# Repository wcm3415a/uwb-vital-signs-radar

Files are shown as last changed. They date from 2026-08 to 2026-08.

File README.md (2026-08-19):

# UWB Radar for Contactless Vital Sign Detection





## 📋 Overview
This repository contains the hardware configuration, firmware, and signal processing software for a proof-of-concept UWB radar system. The objective was to design a contactless Ultra-Wideband (UWB) radar system to detect vital signs for future integration into a mobile robot. This research relies on repurposing low-cost DWM1001-DEV modules into a bistatic radar to extract and analyze the Channel Impulse Response (CIR).

This project was conducted as part of a 4th-year engineering internship at the **HCR Laboratory (Robotics and Embedded Systems)** at **[Ostfalia University of Applied Sciences, Germany](https://www.ostfalia.de)**.

## 📚 Project Documentation (Wiki)
Comprehensive documentation covering the theoretical background, hardware setup, and software architecture is available in the **[Project Wiki](https://github.com/wcm3415a/uwb-vital-signs-radar/wiki)**:
* 📖 **[Hardware Architecture and Test Bench](https://github.com/wcm3415a/uwb-vital-signs-radar/wiki/Hardware-and-Test-Bench):** Details on the bistatic configuration and the 3D-printed electromagnetic shield.
* 📖 **[Firmware and SPI Communication](https://github.com/wcm3415a/uwb-vital-signs-radar/wiki/Firmware-and-SPI):** C++ implementation, register modifications, and SPI throttling.
* 📖 **[DSP Theory and VMD Algorithm](https://github.com/wcm3415a/uwb-vital-signs-radar/wiki/Signal-Processing):** Mathematical foundations of phase extraction and Variational Mode Decomposition.
* 📖 **[Real-Time Python Application](https://github.com/wcm3415a/uwb-vital-signs-radar/wiki/Python-Application):** Multithreaded architecture for high-speed serial parsing and real-time visualization.

## 🛠️ System Architecture
* **Firmware (C++):** A custom low-level firmware developed via PlatformIO bypasses the factory localization features. The transmitter operates at 64 MHz PRF (Channel 5), while the receiver continuously extracts the CIR. SPI communication is throttled to 1 MHz to prevent data corruption.
* **Hardware Mitigation:** A custom 3D-printed shield lined with aluminum prevents receiver saturation caused by direct antenna coupling.
* **Software Pipeline (Python):** An asynchronous multithreaded application parses the 460,800-baud serial stream. It applies an Exponential Moving Average for radar clutter removal, extracts the complex phase (`arctan(Q/I)`), and uses Variational Mode Decomposition (VMD) to isolate physiological frequencies.

## 📊 Experimental Results and Hardware Limitations
The software processing chain was successfully validated on the [MobiVital](https://github.com/nesl/MobiVital-dataset) reference dataset, achieving a respiratory rate estimation error of less than 8%. However, real-world testing on the physical prototype revealed strict hardware limitations:

* **Respiration Extraction:** The system successfully extracts the respiratory signal, allowing the distinction between inspiration and expiration cycles. However, the measurement is affected by a permanent residual noise that cannot be fully compensated by software, occasionally falsifying parts of the obtained results.
* **Heart Rate Extraction (Failed):** Heartbeat extraction failed due to absolute physical limitations. The lack of strict hardware clock synchronization between the two asynchronous boards induces a phase noise (Jitter). This electronic drift completely masks the sub-millimeter cardiac displacement, rendering it unexploitable. Future iterations will strictly require hard-wired clock synchronization.

## 📁 Repository Structure
```text
├── Firmware/                 # C++ PlatformIO project for TX/RX modules
│   ├── src/main.cpp          # Core radar logic and SPI extraction
│   └── lib/                  # DW1000 low-level API headers
├── Software/                 # Python DSP pipeline and analysis scripts
│   ├── analysis_breath_DB.py # Respiratory extraction on MobiVital reference dataset
│   ├── analysis_breath_RT.py # Real-time respiratory extraction from serial UWB stream
│   ├── analysis_puls_DB.py   # Heart rate extraction tests on reference dataset
│   └── fonction_RPM.py       # Core DSP functions (VMD, Phase extraction, EMA filters)
├── Hardware/                 # 3D models (STL/Fusion 360) for the RF shield
└── Docs/                     # Additional documentation and test data
```
##  References
This project and its signal processing methodology are based on the following scientific literature and datasets:

* L. Duan et al., "Non-Contact Detection of Vital Signs Using a UWB Radar Sensor", *IEEE Access*, vol. 6, 2018. [DOI: 10.1109/ACCESS.2018.28581412](https://ieeexplore.ieee.org/document/8581412)
* S. Ma et al., "Radar Vital Signs Detection Method Based on Variational Mode Decomposition and Wavelet Transform", *IEEE Sensors Journal*, 2021. [DOI: 10.1109/JSEN.2022.31528129](https://ieeexplore.ieee.org/document/9728129)
* J. Wang et al., "SSA-VMD for UWB Radar Sensor Vital Sign Extraction", *MDPI Sensors*, vol. 23, 2023. [DOI: 10.3390/s23020756](https://www.mdpi.com/1424-8220/23/2/756)
* G. Paterniani et al., "Radar-Based Monitoring of Vital Signs: A Tutorial Overview", *Proceedings of the IEEE*, vol. 111, no. 3, pp. 277-317, March 2023. [DOI: 10.1109/JPROC.2023.32449295](https://ieeexplore.ieee.org/stamp/stamp.jsp?arnumber=10049295)
* Networked & Embedded Systems Lab (NESL), "MobiVital-dataset", *GitHub Repository*. [Link](https://github.com/nesl/MobiVital-dataset)

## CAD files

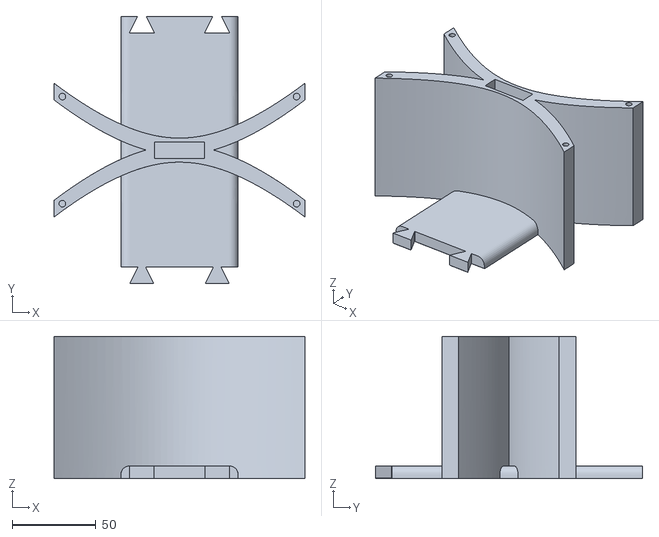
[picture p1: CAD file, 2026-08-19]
Hardware/CentreAvObsB.stl
150.0 x 159.8 x 85.0

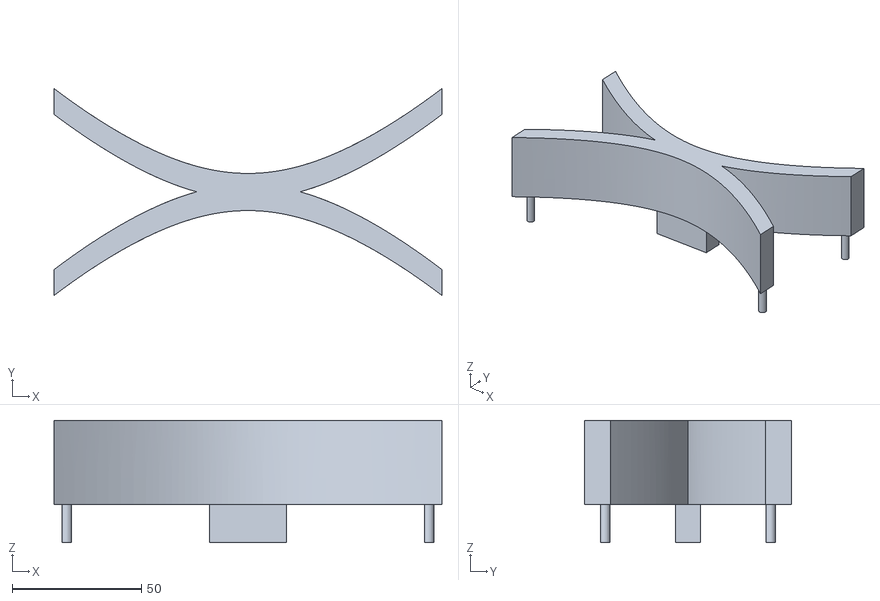
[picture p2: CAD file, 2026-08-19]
Hardware/CentreAvObsH.stl
150.0 x 80.0 x 47.4

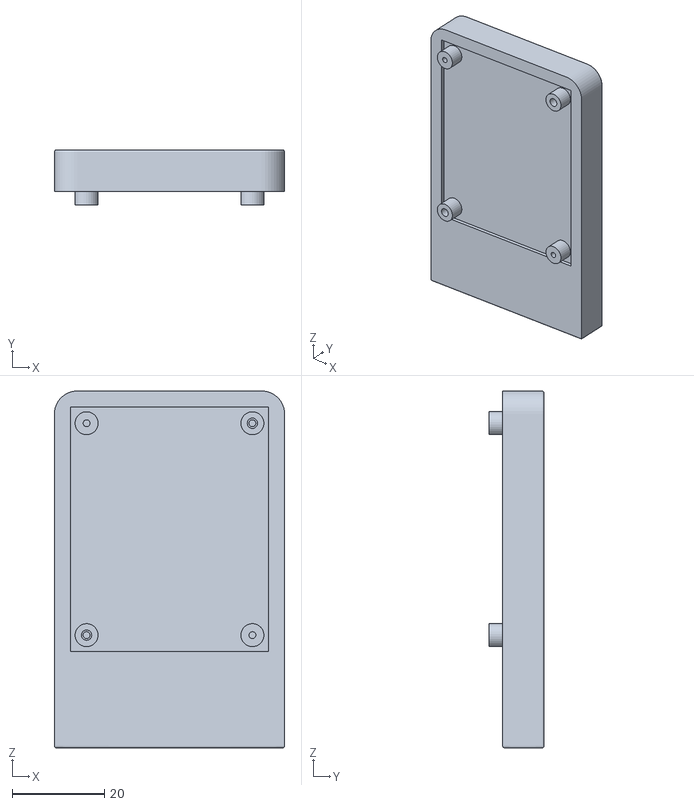
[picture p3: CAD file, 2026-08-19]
Hardware/Support2.stl
50.0 x 12.0 x 77.5

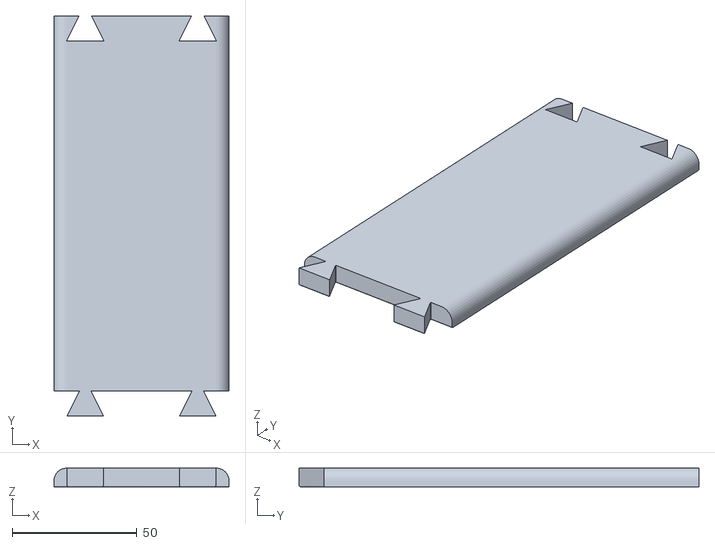
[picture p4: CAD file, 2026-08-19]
Hardware/CentreSaObs.stl
70.0 x 159.8 x 7.50

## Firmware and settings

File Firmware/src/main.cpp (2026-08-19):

#include <Arduino.h>
#include "deca_device_api.h"
#include "deca_regs.h"
 
// --- RADAR ROLE TOGGLE ---
bool is_tx_module = false; 
#define PIN_SW2 2          

extern "C" void port_init(void);

// --- UWB RADIO CONFIGURATION (Radar Special) ---
static dwt_config_t config = {
    5,               // chan           : Radio channel (Channel 5 = 6.5 GHz)
    DWT_PRF_64M,     // prf            : Pulse Repetition Frequency (64 MHz)
    DWT_PLEN_128,    // txPreambLength : Preamble length (128 symbols)
    DWT_PAC8,        // rxPAC          : Preamble Acquisition Chunk 
    9,               // txCode         : TX preamble code 
    9,               // rxCode         : RX preamble code 
    0,               // nsSFD          : Non-standard SFD 
    DWT_BR_6M8,      // dataRate       : Data rate (6.8 Mbps) 
    DWT_PHRMODE_STD, // phrMode        : PHY header mode 
    (129 + 8 - 8)    // sfdTO          : SFD Timeout 
};

void setup() {
    Serial.begin(460800); 
    
    // 1. DEEP SLEEP WAKE-UP
    pinMode(17, OUTPUT);
    digitalWrite(17, LOW);  
    delay(5);               
    digitalWrite(17, HIGH); 
    delay(10);              
    
    // 2. HARDWARE RESET (Pin 24)
    pinMode(24, OUTPUT);
    digitalWrite(24, LOW);  
    delay(10);
    pinMode(24, INPUT);     
    delay(50);              

    // 3. SPI BUS OPENING 
    port_init();
    
    // 4. FORCED PATCH: CAPPING SPI SPEED TO 1 MHz
    #ifdef NRF_SPI2
        NRF_SPI2->FREQUENCY = 0x01000000;
        NRF_SPI2->CONFIG = 0;
    #endif
    #ifdef NRF_SPIM2
        NRF_SPIM2->FREQUENCY = 0x01000000;
        NRF_SPIM2->CONFIG = 0;
    #endif
    #ifdef NRF_SPI1
        NRF_SPI1->FREQUENCY = 0x01000000;
        NRF_SPI1->CONFIG = 0;
    #endif
    #ifdef NRF_SPIM1
        NRF_SPIM1->FREQUENCY = 0x01000000;
        NRF_SPIM1->CONFIG = 0;
    #endif
    
    // 5. DW1000 software initialization
    dwt_softreset();
    
    if (dwt_initialise(DWT_LOADUCODE) != DWT_SUCCESS) {
        while (1) {
            Serial.println("CRITICAL ERROR: The DW1000 chip is not responding on the SPI bus");
            delay(1000);
        }
    }
    
    dwt_configure(&config);
    dwt_setrxantennadelay(16436);

    // --- READING SW2 BUTTON ---
    NRF_P0->PIN_CNF[2] = (3 << 2); 
    delay(10); 

    if ((NRF_P0->IN & (1 << 2)) == 0) {
        is_tx_module = true; 
    } else {
        is_tx_module = false;
    }

    // --- TURNING ON LEDS ---
    NRF_P0->DIRSET = (1 << 14) | (1 << 30);
    NRF_P0->OUTSET = (1 << 14) | (1 << 30);

    if (is_tx_module) {
        Serial.println("Initialising the TX (20 Hz transmitter)...");
        NRF_P0->OUTCLR = (1 << 14); // Turn on Green LED (D9)
    } else {
        Serial.println("Initialising the RX (Radar Recieve)...");
        NRF_P0->OUTCLR = (1 << 30); // Turn on Blue LED (D10)
    }
}

void loop() {
    if (is_tx_module) {
        // --- TX LOGIC ---
        uint8_t tx_msg[] = {'R', 'A', 'D', 'A', 'R', 0, 0}; 

        dwt_writetxdata(sizeof(tx_msg), tx_msg, 0);
        dwt_writetxfctrl(sizeof(tx_msg), 0, 0);
        dwt_starttx(DWT_START_TX_IMMEDIATE);

        while (!(dwt_read32bitreg(SYS_STATUS_ID) & SYS_STATUS_TXFRS)) {
            // Very short wait for the physical transmission
        }
        dwt_write32bitreg(SYS_STATUS_ID, SYS_STATUS_TXFRS); // Unlocks the next shot

        // Wait for 50 milliseconds (20 Hz)
        delay(50); 

    } else {
        // --- RX LOGIC ---
        dwt_rxenable(DWT_START_RX_IMMEDIATE);

        uint32_t status_reg = 0;
        while (!((status_reg = dwt_read32bitreg(SYS_STATUS_ID)) & (SYS_STATUS_RXFCG | SYS_STATUS_ALL_RX_ERR))) {
            // Waiting for the wave...
        }

        if (status_reg & SYS_STATUS_RXFCG) {
            
            // 1. Read the exact index where the wave hit (First Path)
            uint16_t fp_index = dwt_read16bitoffsetreg(RX_TIME_ID, RX_TIME_FP_INDEX_OFFSET);
            uint16_t fp_int = fp_index >> 6; // Convert raw index to integer

            // 2. Step back 10 samples to see the silence right BEFORE the impact
            int16_t start_index = fp_int - 10;
            if (start_index < 0) {
                start_index = 0; 
            }

            // 3. Convert this index to bytes (1 sample = 4 bytes)
            uint16_t byte_offset = start_index * 4;

            // 4. Anti-crash security: prevent reading out of memory bounds (max 4064)
            if (byte_offset > 3000) {
                byte_offset = 3000; 
            }

            // 5. Clear the flag
            dwt_write32bitreg(SYS_STATUS_ID, SYS_STATUS_RXFCG);

            // 6. Read the accumulator with the CORRECT OFFSET
            uint16_t cir_bytes = 1024; 
            uint8_t cir_buffer[cir_bytes + 1]; 

            dwt_readaccdata(cir_buffer, cir_bytes + 1, byte_offset);

            // Send to Mac
            uint8_t header[] = {0xDE, 0xCA, 0xAD, 0xDE}; 
            Serial.write(header, 4);
            Serial.write(&cir_buffer[1], cir_bytes);

        } else {
            dwt_write32bitreg(SYS_STATUS_ID, SYS_STATUS_ALL_RX_ERR);
        }
    }
}

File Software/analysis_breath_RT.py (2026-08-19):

import matplotlib
matplotlib.use('TkAgg')
import matplotlib.pyplot as plt
import matplotlib.animation as animation
import serial
import struct
import numpy as np
import threading
import traceback
import time
import scipy.ndimage as ndimage
from collections import deque
from vmdpy import VMD

# ==========================================
# HARDWARE CONFIGURATION
# ==========================================
PORT = '/dev/cu.usbmodem0007602221481'  
BAUDRATE = 460800
HEADER = b'\xde\xca\xad\xde'
PAYLOAD_SIZE = 1024
NUM_SAMPLES = 256
DISPLAY_BINS = 100

# ==========================================
# CIR & TARGET PARAMETERS
# ==========================================
ALPHA_FAST = 0.1         
ALPHA_ENV = 0.02 
MOTION_THRESHOLD = 800      
TARGET_BIN = 19  # Fixed target at 60 cm
PHASE_PRESENCE_THRESHOLD = 900

# ==========================================
# RESPIRATION & VMD PARAMETERS
# ==========================================
ESTIMATED_FPS = 15
HISTORY_SIZE = 300
DISPLAY_MARGIN = 15
ALPHA_PHASE_SMOOTHING = 0.15
REFERENCE_THRESHOLD = 400

# ==========================================
# GLOBAL VARIABLES
# ==========================================
lock = threading.Lock()
stop_requested = False
first_sample_received = False
REFERENCE_BIN = 0  

# CIR Buffers
cir_median_buffer = deque(maxlen=3) # NEW: Buffer for median filter
raw_cir = np.zeros(NUM_SAMPLES)
smooth_cir = np.zeros(NUM_SAMPLES)
motion_cir = np.zeros(NUM_SAMPLES)
fast_amp = np.zeros(NUM_SAMPLES)
slow_amp = np.zeros(NUM_SAMPLES)

# Temporal Buffers
history_raw_target_phases = deque(maxlen=HISTORY_SIZE)
history_corrected_phases = deque(maxlen=HISTORY_SIZE)

centered_raw_target_signal = np.zeros(HISTORY_SIZE) 
centered_corrected_phase_signal = np.zeros(HISTORY_SIZE) 
vmd_respiratory_signal = np.zeros(HISTORY_SIZE) 

smooth_I_phase, smooth_Q_phase = 0.0, 0.0
first_phase_sample = False

smooth_I_ref, smooth_Q_ref = 0.0, 0.0
first_ref_sample = False

# Buffers for complex smoothing of the difference
smooth_I_diff, smooth_Q_diff = 0.0, 0.0
first_diff_sample = False

# ==========================================
# THREAD 1: RADAR PROCESSING (REAL-TIME)
# ==========================================
def read_serial():
    global raw_cir, smooth_cir, motion_cir, fast_amp, slow_amp
    global smooth_I_phase, smooth_Q_phase, first_phase_sample
    global smooth_I_ref, smooth_Q_ref, first_ref_sample
    global smooth_I_diff, smooth_Q_diff, first_diff_sample
    global first_sample_received, stop_requested
    global centered_raw_target_signal, centered_corrected_phase_signal
    global REFERENCE_BIN, cir_median_buffer
    
    try:
        ser = serial.Serial(PORT, BAUDRATE, timeout=1)
        print("Radar connected. Reading in progress...")
        ser.reset_input_buffer()
    except Exception as e:
        print(f"Connection error: {e}")
        return

    while not stop_requested:
        try:
            ser.read_until(HEADER)
            payload = ser.read(PAYLOAD_SIZE)
            
            if len(payload) == PAYLOAD_SIZE:
                iq_values = struct.unpack('<512h', payload)
                I = np.array(iq_values[0::2], dtype=float)
                Q = np.array(iq_values[1::2], dtype=float)
                
                # --- PRE-PROCESSING ---
                I = I - np.mean(I)
                Q = Q - np.mean(Q)
                I = ndimage.gaussian_filter1d(I, sigma=1.0)
                Q = ndimage.gaussian_filter1d(Q, sigma=1.0)
                
                amplitude = np.sqrt(I**2 + Q**2)

                # --- SOLUTION 2: TEMPORAL MEDIAN FILTER (SLOW-TIME) ---
                cir_median_buffer.append(amplitude)
                if len(cir_median_buffer) == 3:
                    # Apply median on the last 3 received CIRs
                    filtered_amplitude = np.median(cir_median_buffer, axis=0)
                else:
                    filtered_amplitude = amplitude

                with lock:
                    # We now use the stabilized amplitude
                    raw_cir = filtered_amplitude.copy()
                    
                    if not first_sample_received:
                        fast_amp = filtered_amplitude.copy()
                        slow_amp = filtered_amplitude.copy()
                        first_sample_received = True
                    else:
                        fast_amp = (ALPHA_FAST * filtered_amplitude) + ((1 - ALPHA_FAST) * fast_amp)
                        slow_amp = (ALPHA_ENV * filtered_amplitude) + ((1 - ALPHA_ENV) * slow_amp)
                        
                    smooth_cir = slow_amp.copy()
                    motion_cir = np.abs(fast_amp - slow_amp)
                    motion_cir[motion_cir < MOTION_THRESHOLD] = 0

                    # --- REFERENCE LOCKING ---
                    search_amp = slow_amp[:DISPLAY_BINS].copy()
                    idx_peak1 = np.argmax(search_amp)
                    upper_bound = min(DISPLAY_BINS, idx_peak1 + 5)
                    search_amp[:upper_bound] = 0 
                    
                    new_ref_bin = np.argmax(search_amp)
                    max_search_val = search_amp[new_ref_bin]
                    current_ref_val = slow_amp[REFERENCE_BIN] if REFERENCE_BIN < DISPLAY_BINS else 0

                    if max_search_val > REFERENCE_THRESHOLD:
                        if REFERENCE_BIN == 0 or current_ref_val < REFERENCE_THRESHOLD or max_search_val > current_ref_val * 1.50:
                            if new_ref_bin != REFERENCE_BIN:
                                REFERENCE_BIN = new_ref_bin
                                first_ref_sample = False
                                first_diff_sample = False 
                                history_raw_target_phases.clear()
                                history_corrected_phases.clear()
                                centered_raw_target_signal.fill(0)
                                centered_corrected_phase_signal.fill(0)
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

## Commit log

2026-08-18 Correction et ajout du code source Firmware
    [main.cpp, port.c]
2026-08-18 Ajout de la librairie decadriver dans le dossier lib
2026-08-19 add meshe file
    [CentreAvObsB.stl, CentreAvObsH.stl, CentreSaObs.stl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]
